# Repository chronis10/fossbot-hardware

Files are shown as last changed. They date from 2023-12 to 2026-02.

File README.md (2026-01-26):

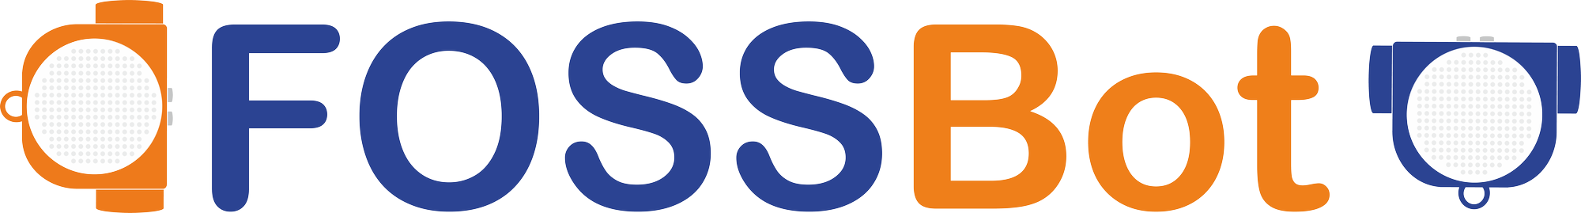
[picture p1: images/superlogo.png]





The newer version of the FOSSBot is available here, where you can find the 3D models and instructions to build it.

The redesign of the robot is complete, and the files are available for download.

The circuit schematics, instructions, and firmware code will be available soon.

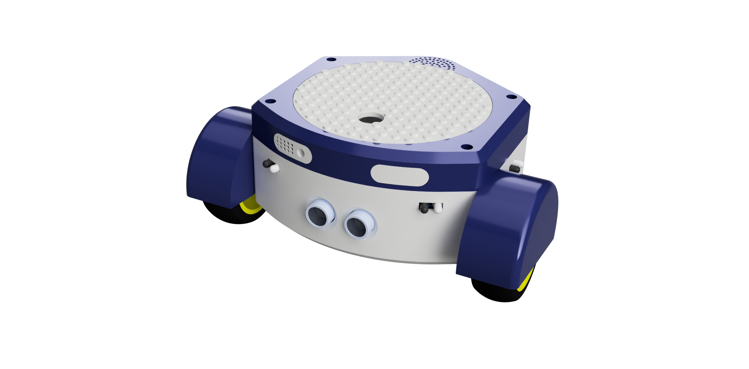
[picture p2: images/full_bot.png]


## 3D Printable Part List
---
* [Battery Cover](stl/batterycover.stl)
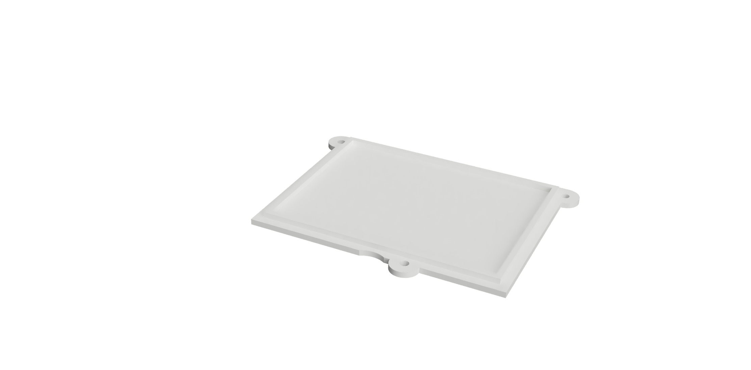
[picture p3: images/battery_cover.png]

---
* [Bottom Base](stl/b1_p_f.stl)
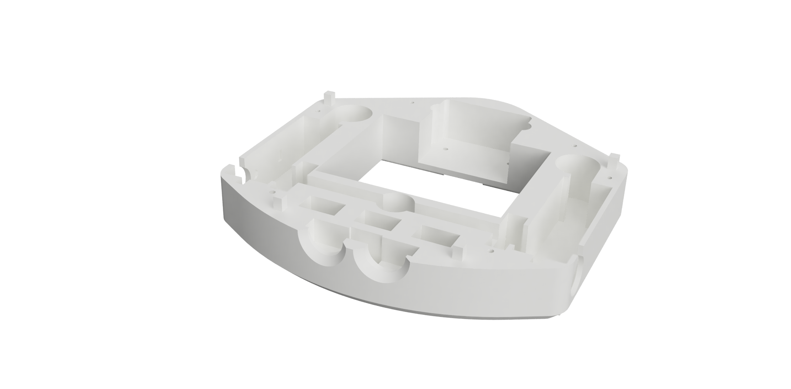
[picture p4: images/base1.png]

---
* [Middle Base](stl/b2_p_f.stl)
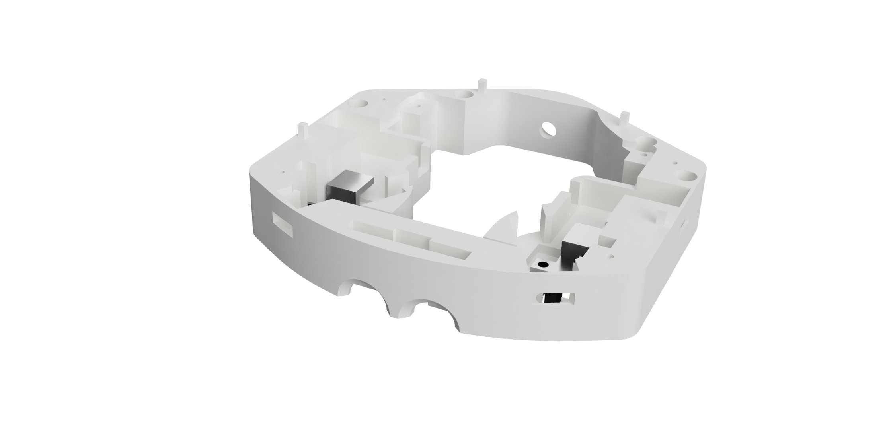
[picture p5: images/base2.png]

---
* [Top Base](stl/b3_p_f.stl)
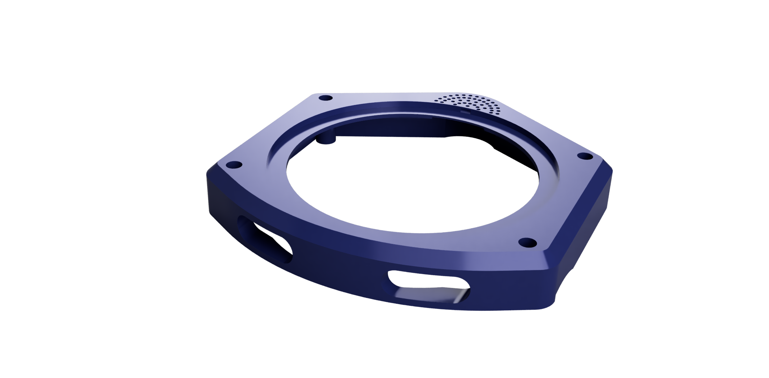
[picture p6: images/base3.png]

---
* [Left eye](stl/left_eye.stl)
* [Right eye](stl/right_eye.stl)
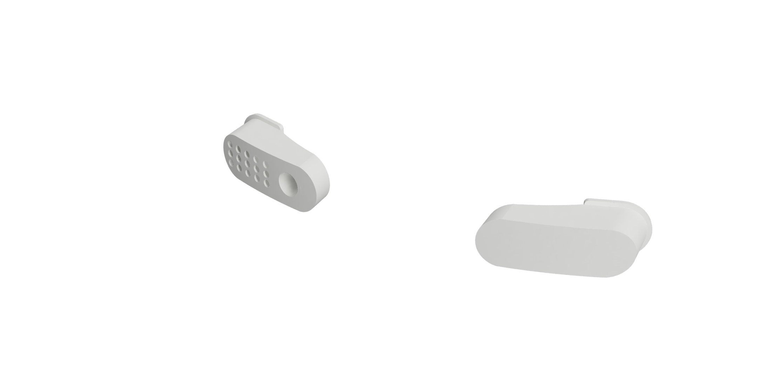
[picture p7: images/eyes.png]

---
* [Top Cover](stl/lego_top.stl)
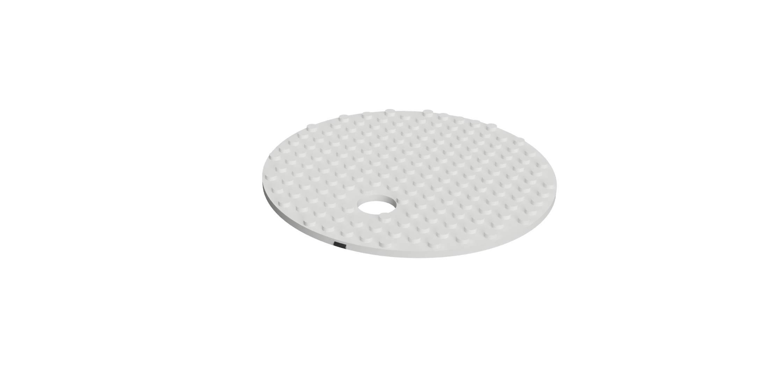
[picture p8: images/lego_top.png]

---
* [Pen Holder](stl/pen_holder.stl)
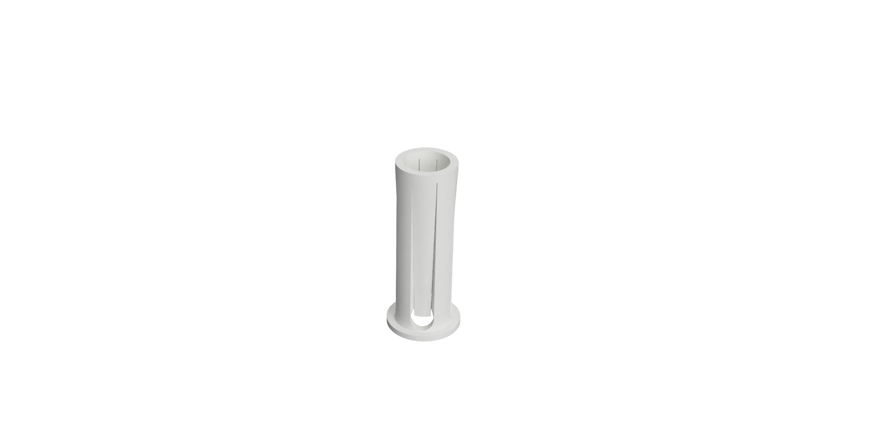
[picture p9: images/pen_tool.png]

---
* [Spoiler Left](stl/fender_left.stl)
* [Spoiler Right](stl/fender_right.stl)
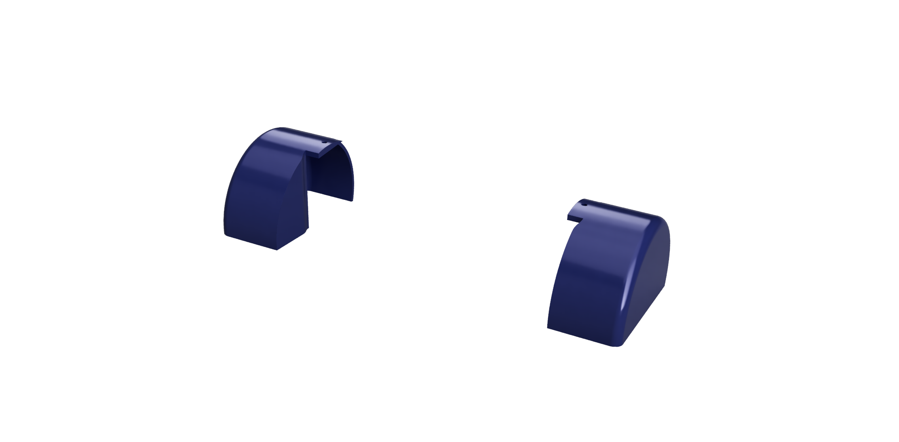
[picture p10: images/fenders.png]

---

## PCB
---
* [Main PCB production file](PCB/production/fossbot-v2-main-pcb.zip)
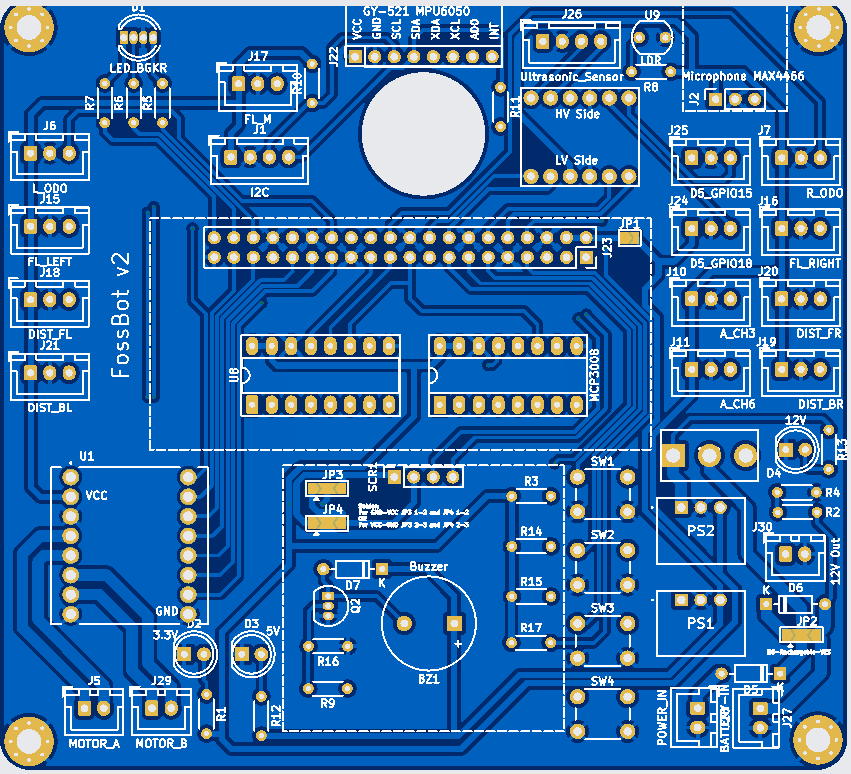
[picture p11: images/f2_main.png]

---
* [Battery module production file](PCB/production/battery_module.zip)
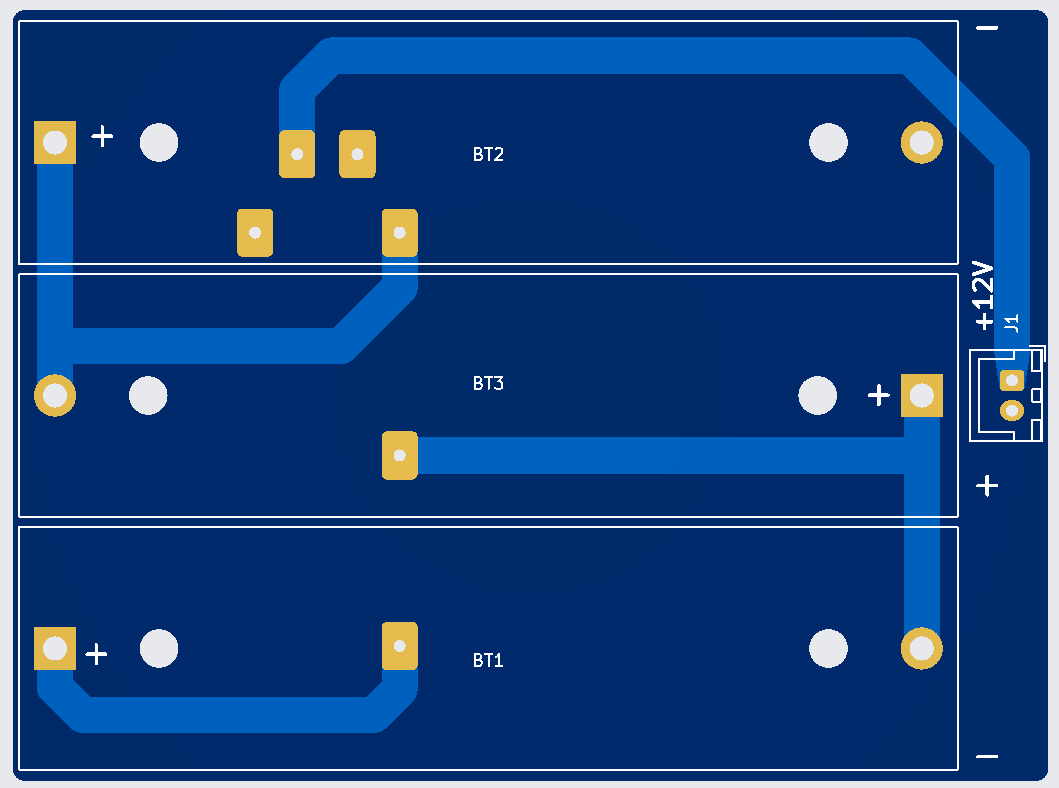
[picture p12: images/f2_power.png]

---

## Hardware/Software Development Team
* Christos Chronis
* Dimitris Charitos
* Adrien BRACQ - Barbatronic

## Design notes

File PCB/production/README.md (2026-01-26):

# Production Files

Upload these ZIP files directly to a manufacturer to produce the PCBs.
You can use https://jlcpcb.com/ , which has already been tested by our team with good results, but feel free to try alternative manufacturers.

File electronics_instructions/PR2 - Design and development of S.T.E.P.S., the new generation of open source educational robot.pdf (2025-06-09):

Design and development of S.T.E.P.S.,

# the new generation of open source educational robot

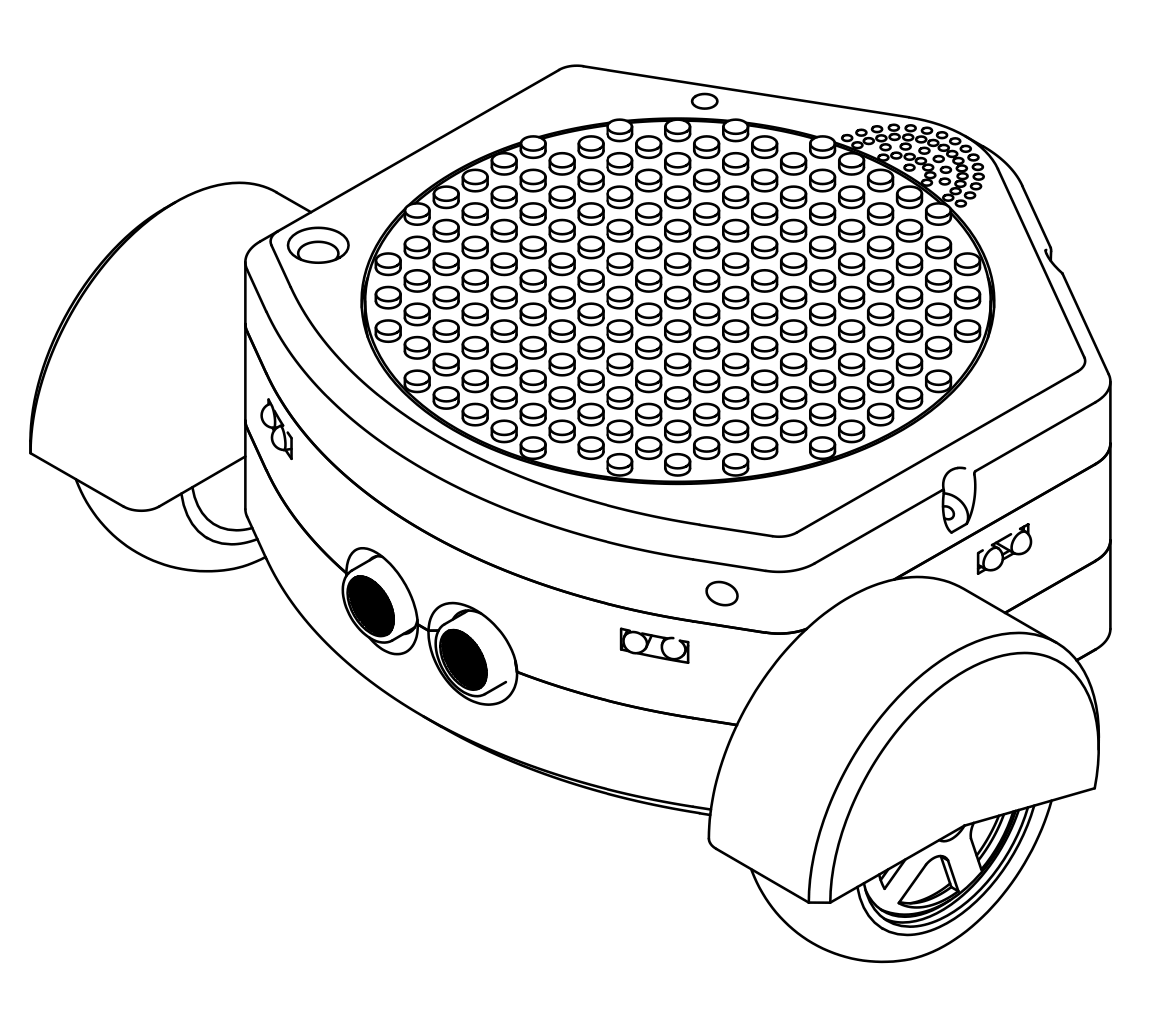
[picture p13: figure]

1. Executive Summary | 4
1.1. Overview of the S.T.E.P.S. project | 4
1.2. Objectives of the New Design | 5
1.3. Key Innovations and Improvements | 6
1.4. Target Audience and Use Cases | 8
2. Background and Inspiration | 9
2.1. Overview of FOSSBot: The Open-Source Educational Robot | 9
2.2. Limitations and Challenges of FOSSBot | 12
2.3. Desk Research Insights from 5 Countries | 12
2.4. Initial Aims: Simplification and Usability | 14
3. Design Philosophy and Goals | 17
3.1. Core Design Principles | 17
3.2. Focus on Open-Source and Accessibility | 17
3.3. Simplification of Assembly and Usage | 18
3.4. Modularity and Customizability | 19
3.5. Alignment with Educational Standards | 20
4. Development Process | 21
4.1. Conceptualization and Ideation | 21
4.2. Iterative Design and Prototyping | 21
4.3. Incorporating Feedback from Desk Research | 22
4.4. Collaboration with Open-Source Communities | 22
4.5. Challenges and Solutions | 22
5. Technical Design of the new FOSSBot | 24
5.1. Mechanical Design | 24
5.2. Electronics Design | 27
5.3 Software Architecture and Connectivity | 29
6. Key Features and Innovations | 31
6.1. Simplified Assembly Process | 31
6.2. Enhanced Durability and Usability | 31
6.3. Support for Multiple Programming Levels | 32
6.4. Expandable and Customizable Modules | 32
6.5. Cost-Effective and Open-Source Design | 32
7. Comparison with FOSSBot | 33
7.1. Design and Structural Improvements | 33
7.2. Enhanced Educational Features | 33
7.3. Usability and Accessibility Comparison | 33
7.4. Cost and Manufacturing Efficiency | 34
8. Conclusion | 35
8.1. Summary of Achievements | 35

8.2. Im

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
al R

o

b

o

tic

s

3

6
8.3. C

all t

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
# 1. Executive Summary

## 1.1. Overview of the S.T.E.P.S. project

S.T.E.P.S. (STEM Teaching and Education Platform for Students) is a project designed to democratize access to robotics and STEM education, utilizing open-source technologies and free software to make educational resources more accessible and customizable for students and educators from various backgrounds. Leveraging open-source solutions and tools, as well as the best practices of STEM education across several countries, it aims to make robotics and programming accessible to students and their educators.

At its core, S.T.E.P.S. provides low-cost, customizable educational robots that empower students and educators to explore robotics and programming in a hands-on manner. By leveraging open-source principles, the project ensures that its tools and resources are freely available, enabling widespread adoption even in underserved communities. Complementing the hardware, S.T.E.P.S. includes manuals, guidelines, sample programs, etc., offering free access to high-quality STEM learning resources, tutorials, and project ideas. This combination of physical and digital tools creates a comprehensive ecosystem for learning and innovation.

The project brings together experts from diverse fields, including robotics, education, software development, and sustainability, to collaboratively design tools, guidelines, and educational content tailored to a wide range of learners. By addressing Erasmus+ priorities, S.T.E.P.S. promotes digital transformation, inclusion, and diversity in education, ensuring that no one is left behind in the rapidly evolving digital landscape. The initiative is designed to support pre- and in-service secondary school teachers or trainers who aim to teach STEM and robotics to beginners, as well as students from all backgrounds, particularly those in secondary schools and beyond, who are eager to learn robotics and programming. Additionally, S.T.E.P.S. engages educational institutions, authorities, and policymakers to foster systemic change, while also involving parents or guardians who wish to support their children’s STEM education.

The project also welcomes community members, including local businesses and organizations, to contribute to STEM education initiatives in their areas, and it actively collaborates with open-source communities and developers to enhance the educational robot and MOOC platform. Furthermore, S.T.E.P.S. encourages primary school teachers to integrate STEM into their curriculum and invites university students or recent graduates to volunteer as mentors or instructors, creating a vibrant ecosystem of learning and collaboration. To align with global sustainability goals, the project incorporates green practices, such as using sustainable materials in robot production and adopting energy-efficient design principles. Through these efforts, S.T.E.P.S. not only advances STEM education but also embodies a forward-thinking, socially responsible approach that benefits learners, educators, and communities alike.

After performing an overview of open source software and hardware solutions and based on the previous experience of the team on designing educational robots, we decided to rely on the open source robot FOSSBot, and instead of designing a new robot from scratch, we decided to upgrade it.

## 1.2. Objectives of the New Design

The design of S.T.E.P.S. is driven by clear, measurable objectives aimed at making STEM education more accessible, engaging, and effective. These objectives focus on simplifying assembly and usage, enhancing educational value, promoting open-source collaboration, and ensuring affordability. Each objective is supported by specific design improvements and key performance indicators (KPIs) to track progress and success.

1. Simplify Assembly and Usage
One of the primary goals of S.T.E.P.S. is to reduce the complexity of building and operating the robot, making it accessible to beginners, including students and educators with limited technical expertise. To achieve this, the robot’s body and electronic components have been redesigned to allow for an easier assembly process. This includes modular components that snap together without the need for specialized tools, as well as clear, step-by-step instructions. Additionally, the project aims to reduce 3D printing time and material usage by optimizing the design for efficiency. Quantitative KPIs, such as the percentage reduction in printing materials and time, will be tracked to measure success. User feedback on the ease of assembly will also be collected through the LTTA workshops, ensuring continuous improvement based on real-world experiences.
2. Enhance Educational Value
S.T.E.P.S. is designed to provide a versatile platform that supports multiple programming levels, catering to users with varying skill levels. Beginners can start with the kindergarten mode which contains only 4 movement buttons and continue with block-based coding (using Blockly). The user interface (UI) is intuitive and adaptable, ensuring a seamless learning experience. To measure the success of this objective we will gather qualitative feedback through online surveys on the usability of the UI and its educational value. Additionally, the robot will feature new sensors, to expand its capabilities and applications.
3. Promote Open-Source Collaboration
S.T.E.P.S. is committed to fostering a vibrant open-source community where users can contribute to the development and improvement of the robot. By extending FOSSBot and generating FOSSBot 2.0, we will be able to encourage collaboration among educators, students, developers, and hobbyists. To further assist users who do not have the ability to print and assemble the robot immediately, we also provide a simulated version of the robot developed using CoppeliaSim. The digital twin allows users to simulate and test the robot in a virtual environment, further lowering barriers to entry. The simulated version and all design files, software, and documentation of the new robot are freely available through the FOSSBot github page (https://github.com/eellak/fossbot) Qualitative feedback from the community will be collected to assess the relevance and impact of the open-source approach.
4. Ensure Affordability
To enable widespread adoption, particularly in schools and underserved communities, the new FOSSBot is designed to be cost-effective. The optimized design reduces material and production costs, while the use of 3D printing allows for local manufacturing, further lowering expenses. Affordability will be measured through quantitative KPIs, such as the percentage reduction in material costs, and qualitative feedback from educators and institutions on the robot’s accessibility.

The success of FOSSBot redesign will be evaluated through a combination of quantitative and qualitative KPIs. Quantitative metrics include the percentage reduction in printing materials and time, the number of new sensors and expansion capabilities, the number of programming tools supported by the UI, and the number of downloads and users of the digital twin. Qualitative KPIs will focus on user feedback, collected through online surveys and assessing the ease of assembly, usability of the UI, educational value, and relevance to curricula. These metrics will ensure that the project remains aligned with its goals and continuously improves based on user needs.

By focusing on these objectives and tracking progress through well-defined KPIs, S.T.E.P.S. aims to create a transformative educational tool that empowers learners, supports educators, and fosters innovation in STEM education.

## 1.3. Key Innovations and Improvements

S.T.E.P.S. introduces a range of key innovations and improvements over the original FOSSBot, now referred to as FOSSBot 2.0. These advancements are designed to enhance functionality, usability, and accessibility, making the robot a more versatile and effective tool for STEM education. Below are the major innovations that define FOSSBot 2.0:

1. Integration of Raspberry Pi
One of the most significant upgrades in FOSSBot 2.0 is the integration of a Raspberry Pi as the main processing unit. This powerful microcontroller not only supports a wide range of sensors and peripherals but also allows the robot to function as a web server, hosting its own programming platform. This means users can program the robot directly through a web interface, eliminating the need for additional software installations. The Raspberry Pi’s versatility opens up new possibilities for advanced projects, such as data logging, machine learning, and IoT applications, making FOSSBot 2.0 a future-proof educational tool.
2. Wireless Connectivity
FOSSBot 2.0 introduces Wi-Fi connectivity, enabling users to connect to the robot wirelessly. This eliminates the need for cables or USB connections to transfer programs, making the robot more convenient and user-friendly. Wireless connectivity also allows for real-time control and monitoring, enhancing the interactive learning experience. Students can program and control the robot from their laptops, tablets, or smartphones, fostering a more flexible and engaging learning environment.
3. New PCB Design
The robot features a new printed circuit board (PCB) that integrates multiple circuits, significantly reducing the number of cables and connections required. This streamlined design not only simplifies assembly but also improves reliability by minimizing potential points of failure. The new PCB also includes JST clips for easy sensor attachment and replacement, making it easier for users to customize and upgrade the robot.
4. Modular Plastic Design
FOSSBot 2.0 incorporates a modular design for its 3D-printed plastic components, which minimizes assembly time and simplifies maintenance. The modular approach allows users to easily replace or upgrade individual parts without disassembling the entire robot. Additionally, the careful placement of sensors and cables reduces the overall size of the robot and optimizes printing time, making it more efficient to produce.
5. Simulation in CoppeliaSim
To lower the barrier to entry, FOSSBot 2.0 includes a digital twin simulation in CoppeliaSim. This allows users to program and test the robot in a virtual environment without the need for physical hardware. The simulation is particularly useful for educators and students who may not have immediate access to the robot, providing a no-cost way to explore its programming philosophy and capabilities.
6. LEGO-Compatible Top
The robot’s top panel is designed to be LEGO-compatible, enabling users to attach additional components and accessories. This feature encourages creativity and experimentation, allowing students to build custom extensions and integrate the robot with other LEGO-based projects. The top panel is also attached with magnets, making it easy to open and access the internal components for maintenance or upgrades.
7. Battery Compatibility and Accessibility
FOSSBot 2.0 supports rechargeable lithium batteries as well as other commonly available battery types, ensuring flexibility and accessibility for users with different resources. The battery compartment features a removable bottom cover, making it easy to replace batteries without disassembling the robot. This design choice enhances usability and ensures the robot can be powered by whatever batteries are readily available.
8. Robust and Durable Design
The robot’s sturdy and durable design ensures it can withstand the rigors of classroom use. The materials and construction are optimized for longevity, reducing the need for frequent repairs or replacements. This durability makes FOSSBot 2.0 a reliable tool for educators and students alike.
9. Additional Sensors and Expandability
FOSSBot 2.0 includes more sensors than its predecessor, expanding its capabilities for educational projects. The robot also features I2C connectivity, allowing for the easy integration of additional components and peripherals. This expandability ensures that the robot can grow with the user’s skills and interests, supporting more advanced projects as learners progress.
10. Improved Software Connectivity
The software architecture of FOSSBot 2.0 has been enhanced to improve connectivity and compatibility with various programming tools and platforms. This ensures a seamless experience for users, whether they are working with block-based coding environments like Blockly or text-based languages like Python and JavaScript.
11. Compact Size
The overall size of FOSSBot 2.0 has been reduced, making it more portable and easier to handle. Despite its smaller footprint, the robot retains all its functionality and expandability, ensuring it remains a powerful tool for STEM education.

These innovations collectively make FOSSBot 2.0 a cutting-edge educational robot that is easier to use, more versatile, and more accessible than ever before. By addressing the limitations of the original FOSSBot and incorporating user feedback, S.T.E.P.S. has created a tool that empowers learners and educators to explore the exciting world of robotics and programming.

## 1.4. Target Audience and Use Cases

S.T.E.P.S. is designed to cater to a diverse audience, ensuring that its benefits reach a wide range of users across educational and community settings. The robot and its accompanying resources are tailored to meet the needs of various target groups, each with unique goals and requirements.

1. Educators and Trainers
Pre- and in-service secondary school teachers or trainers form a core part of S.T.E.P.S.’s target audience. These educators are often tasked with introducing STEM and robotics to students at a beginner level but may lack the tools or confidence to do so effectively. S.T.E.P.S. addresses this challenge by providing an easy-to-assemble robot, comprehensive lesson plans, and a user-friendly programming interface. Teachers can use the robot to teach fundamental concepts in robotics, programming, and engineering, while also fostering problem-solving and critical thinking skills. Additionally, primary school teachers who wish to incorporate STEM education into their curriculum can leverage S.T.E.P.S. to introduce younger students to basic robotics concepts in an engaging and age-appropriate manner.
2. Students and Learners
Students from all backgrounds, particularly those in secondary schools and beyond, are a key focus of S.T.E.P.S. The robot is designed to be accessible to beginners, allowing students with no prior experience in robotics or programming to get started quickly. At the same time, its advanced features and expandable capabilities provide opportunities for more experienced learners to explore complex concepts and projects. By supporting multiple programming levels—from block-based coding for beginners to text-based programming for advanced users—S.T.E.P.S. ensures that students can progress at their own pace. The robot’s hands-on nature makes it an ideal tool for project-based learning, enabling students to apply theoretical knowledge to real-world challenges.
3. Institutions, Policymakers, and Community Stakeholders
Educational institutions and authorities play a crucial role in the adoption and implementation of STEM education initiatives. S.T.E.P.S. provides these stakeholders with a cost-effective, scalable solution that aligns with curriculum standards and promotes digital transformation. Policymakers can use the project as a model for integrating robotics and programming into national or regional education frameworks. Beyond formal education, community members, including local businesses and organizations, can support STEM education initiatives by sponsoring S.T.E.P.S. kits or hosting workshops. This collaborative approach helps build a strong ecosystem of learning and innovation at the community level.
4. Open-Source Contributors and Mentors
S.T.E.P.S. actively engages open-source communities and developers to contribute to the ongoing development and improvement of the robot and its accompanying MOOC platform. By making all design files, software, and documentation freely available, the project encourages collaboration and innovation. Additionally, university students or recent graduates can volunteer as mentors or instructors, sharing their expertise with younger learners and gaining valuable teaching experience. This not only enriches the learning experience for students but also fosters a sense of community and shared purpose among contributors.

Through its inclusive design and versatile applications, S.T.E.P.S. serves as a powerful tool for empowering learners, supporting educators, and engaging communities in the exciting world of STEM and robotics.

# 2. Background and Inspiration

## 2.1. Overview of FOSSBot: The Open-Source Educational Robot

FOSSBot is an educational robot that uses open software and hardware and can be employed at all levels of education. FOSSBot has been developed collaboratively by Harokopio University of Athens and GFOSS, and is an extension of "GSOC 2019 - A DIY robot kit for educators" https://github.com/eellak/gsoc2019-diyrobot. As a DIY (Do It Yourself) robot, FOSSBot is designed to be easily built, disassembled, and reassembled by users, making the construction process itself an integral part of the educational experience. The robot’s components are intentionally simple and affordable, with electronic parts that are commercially available at low cost and 3D-printable plastic parts, ensuring accessibility for schools, educators, and hobbyists.

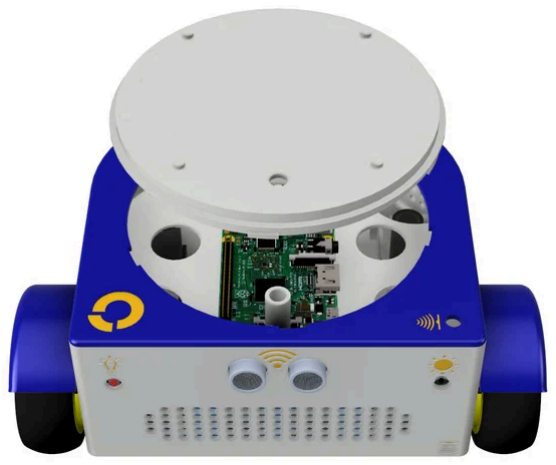
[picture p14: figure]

Figure 1. The top-view and internal aspect of FOSSBot’s initial design

FOSSBot is equipped with a variety of sensors and features that make it a powerful tool for teaching robotics and programming. Its sensors include an ultrasonic distance sensor, battery sensor, accelerometer, gyroscope, odometers, IR receiver, line detection sensors, and light sensors, enabling a wide range of educational activities and experiments. The robot also boasts interaction features such as a speaker, front RGB LED, and a top cover for attaching additional components. Practical design elements, like a hole in the front for marker or pencil attachment and a special pulling loop, further enhance its usability in classroom settings. Additionally, FOSSBot is powered by rechargeable batteries, making it an eco-friendly and cost-effective solution for hands-on learning. These features,combined with its open-source nature, make FOSSBot a highly adaptable and engaging platform for STEM education.

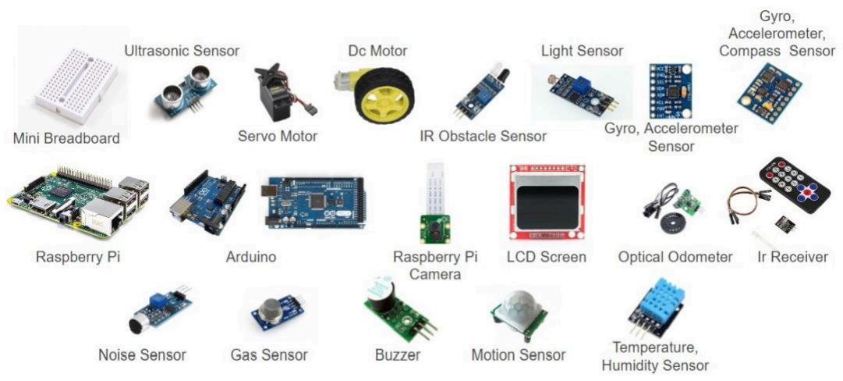
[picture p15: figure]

Figure 2. The list of FOSSBot electronics

FOSSBot is operated on a modular software stack that enables a variety of operation and programming modes, seamless orchestration through its administration GUI, and straightforward hardware control via a Python-based software library that functions as the robot’s operating system. The stack integrates several interconnected components, including Google Blockly for block-based programming, Python Jupyter for interactive coding, and Python Flask, which hosts the administration and supervisor GUI. At its core, FOSSBot relies on a Python library that abstracts hardware control, allowing users to easily command the robot’s movements, sensors, and actuators. This core library is accessible to all programming and operation modules, ensuring a unified and flexible development environment. The administration container oversees the robot’s normal operation, enabling users to modify default parameters and maintain the system. While FOSSBot’s current capabilities focus on basic 2D movement and sensor data collection, future development aims to expand its functionality with advanced features such as path planning and computer vision. Additionally, the system supports no-coding and block-based coding modes through a middleware interface that wraps core functionalities into REST API calls, ensuring accessibility for users of all skill levels. This modular and extensible architecture positions FOSSBot as a versatile platform for educational robotics.

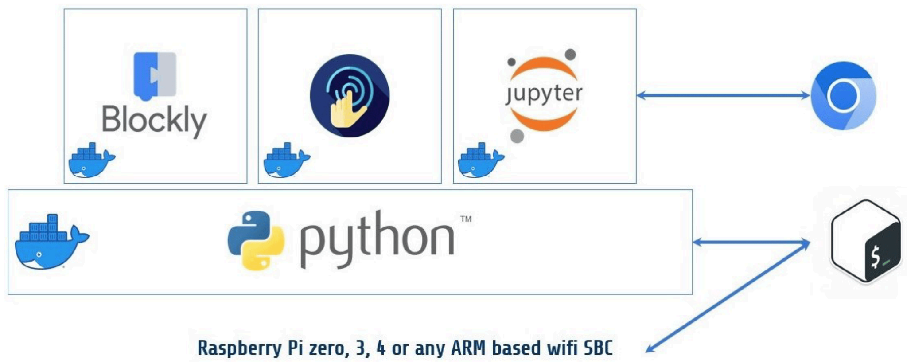
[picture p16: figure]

Figure 3. The programming stack of FOSSBot

FOSSBot offers four distinct programming modes, each tailored to different skill levels and educational needs. The first mode, No-Coding Mode, is designed for users with little or no programming experience, such as pre-school children. In this mode, the robot is operated through a simple graphical interface with buttons that control basic movements like forward, backward, and rotational steps. Educators can customize this interface by adding new buttons linked to pre-defined or block-based scripts, enabling activities like line-following or sound playback. This mode not only introduces young learners to robotics but also allows educators to adjust the complexity of tasks based on the students’ progress. The second mode, Block-Based Coding Mode, is ideal for primary school students and is built on the open-source Google Blockly platform. Here, users create programs by connecting coding blocks that represent commands, such as movement, sensor interactions, and LED control. These blocks are mapped to Python methods in the core FOSSBot library, allowing students to control the robot’s hardware without writing code. The block-based scripts can be saved, modified, and even linked to buttons in the No-Coding Mode, providing a seamless transition between modes. This approach fosters computational thinking and problem-solving skills in a visual and intuitive way. Together, these two modes make FOSSBot accessible to beginners while gradually preparing them for more advanced programming challenges.

## 2.2. Limitations and Challenges of FOSSBot

Despite its innovative design and educational potential, the original FOSSBot faced several limitations and challenges that hindered its accessibility and usability, particularly for beginners and educators with limited technical expertise. One of the most significant issues was the complexity of assembly, which required users to manually connect multiple electronic components without the aid of a printed circuit board (PCB). This not only increased the risk of wiring errors but also made the assembly process time-consuming and intimidating for those unfamiliar with electronics. Additionally, the 3D printing of plastic parts was both time-intensive and material-heavy, further delaying the readiness of the robot for classroom use. These factors combined to create a steep learning curve, limiting FOSSBot’s adoption in educational settings where simplicity and ease of use are critical.
Another challenge was the lack of modularity and user-friendly design in the original FOSSBot. The absence of a unified PCB meant that cables and connections were exposed and prone to disconnection, making the robot less durable and harder to maintain. Furthermore, the assembly process required specialized tools and a certain level of technical skill, which posed a barrier for educators and students who were not familiar with electronics or robotics. The long printing and assembly times also made it difficult to integrate FOSSBot into time-constrained classroom activities, reducing its practicality as an educational tool. Additionally, the battery charging circuit added to the cost and complexity of the robot, as it required specific components and careful assembly, further limiting its accessibility for schools with limited budgets or technical resources.
A notable usability challenge was the initial connection process, which required users to connect to FOSSBot as a hotspot. While this allowed for wireless interaction, the setup process was not always intuitive, especially for younger students or educators unfamiliar with networking concepts. This created a barrier to entry, as users had to navigate multiple steps to establish a connection before they could begin programming or controlling the robot. Moreover, while FOSSBot offered multiple programming modes, not all of them were equally useful or relevant for its primary target audience of primary and secondary education. For example, the Python programming mode, which provided low-level control over the robot, was often too advanced for younger students, while the no-coding and block-based modes were more aligned with their skill levels. This mismatch in programming modes highlighted the need for a more focused and streamlined approach to ensure that the robot’s features were both accessible and educationally relevant for its intended users.
These challenges underscored the importance of redesigning FOSSBot to address these pain points, leading to the development of FOSSBot 2.0, which incorporates a new PCB, modular design, simplified battery compatibility, and a more intuitive connection process. By focusing on the needs of primary and secondary education, FOSSBot 2.0 aims to overcome these limitations and make STEM education more inclusive, engaging, and effective.

## 2.3. Desk Research Insights from 5 Countries

The development of S.T.E.P.S. and the redesign of FOSSBot were informed by extensive desk research conducted across five countries: France, Greece, Poland, Spain, and Turkey. This research, which included a review of educational policies, curricula, and best practices, highlighted both the opportunities and challenges of integrating educational robotics (ER) and STEM education into school systems. A key resource in this research was the book chapter that has been published by the S.T.E.P.S. consortium in a Springer Palgrave book. The chapter was titled "Theoretical and Practical Coherence of Integrated STEM Education and Educational Robotics: Review and Analysis of Good Practices in Europe", co-authored by experts from the S.T.E.P.S. project. This chapter analyzed ten best practices in ER and STEM education across Europe, identifying common trends, challenges, and areas for improvement.
The desk research analyzed 50 good practices across the five European countries, focusing on four key parameters: teaching methodologies, promotion of co-education, types of robots used, and integration of STEM areas. The findings revealed that cooperative and collaborative learning was the most prevalent teaching methodology, used in 46 out of 50 practices, followed by constructionism (23 practices) and project-based learning (PBL) (21 practices). These methodologies emphasize interactive, hands-on, and group-based learning, which are highly effective in engaging students and fostering critical thinking. However, the research also highlighted a significant gap in co-education, with 88% of practices failing to address gender equality. This underscores the need for more initiatives to encourage girls to pursue STEM studies and ensure inclusivity in robotics education.
In terms of robotic resources, the analysis showed a preference for custom-built robots and Lego Mindstorms kits, each used in 15 practices, while Arduino boards were utilized in 6 practices. This indicates a trend toward both low-cost, customizable solutions and commercially available kits, depending on the educational context. The integration of STEM disciplines varied, with technology and engineering being the most commonly integrated areas (over 90% of practices), followed by science (70%) and mathematics (62%). This suggests that while robotics naturally aligns with technology and engineering, there is room for improvement in integrating mathematics and science more cohesively into ER activities.
The research also examined the good practices by country, revealing distinct trends and preferences. For example:
- France favored self-built robots using low-cost materials and emphasized cooperative learning and constructionism. However, it lagged in integrating mathematics and science into its practices.
- Spain and Greece showed a strong preference for Lego Mindstorms kits and project-based learning, with Spain also leading in the promotion of co-education.
- Poland stood out for its diverse use of robot types and its focus on co-education, with four practices explicitly addressing gender equality.
- Turkey and Greece demonstrated robust integration of all four STEM areas, though Turkey faced challenges in teacher training and resource accessibility.
One of the most significant findings was the lack of compulsory integration of ER into national curricula across Europe. While countries like Spain and France have made strides in incorporating robotics into their educational frameworks, ER is often relegated to extracurricular activities, weekend workshops, or summer camps. For example, Spain’s 2022 Royal Decree introduced a compulsory "computational thinking, automation, and robotics" block in secondary education, but similar mandates are rare in other countries. In Greece, robotics is taught within the context of informatics and supported by initiatives like the "Skills Workshops" program, but it remains optional. This inconsistency highlights the need for a more standardized approach to ER integration, ensuring that all students, regardless of location or socio-economic status, have access to robotics education.

The research also revealed common barriers to ER adoption, including high equipment costs, lack of trained teachers, and insufficient infrastructure. For instance, while France’s 2015 Digital Plan for Education accelerated the integration of robotics, many schools still struggle with the cost of commercial robot kits and the need for specialized laboratories. Similarly, in Turkey, despite significant advancements in STEM education through initiatives like TÜBİTAK and TEKNOFEST, challenges such as unequal access to resources and inadequate teacher training persist. These findings underscored the importance of developing low-cost, open-source solutions like FOSSBot, which can be easily replicated and adapted to different educational contexts.
Another critical insight was the need for interdisciplinary and project-based learning in STEM education. The reviewed best practices emphasized the importance of integrating at least two STEM disciplines in a cohesive manner, using methodologies like inquiry-based learning and the engineering design process. For example, Poland’s educational policy promotes an interdisciplinary approach that combines sciences and arts, fostering creativity and critical thinking. Similarly, Greece’s recent investment in robotics and STEM equipment, funded by the EU’s National Recovery and Resilience Plan, aims to enhance hands-on, collaborative learning experiences. These findings informed the design of S.T.E.P.S., which emphasizes modularity, expandability, and the use of open-source tools to support diverse educational activities.
The research also highlighted the gender gap in STEM and robotics education, with a notable lack of initiatives aimed at encouraging girls to pursue STEM studies. While countries like Turkey have made efforts to promote co-education and gender equality in STEM, more work is needed to address this issue across Europe. This insight reinforced the need for inclusive design and educational content that appeals to all students, regardless of gender.
Finally, the desk research underscored the importance of teacher training and support in successfully implementing ER and STEM education. Many of the challenges identified, such as the lack of robotics teachers and the complexity of integrating new technologies into the classroom, can be addressed through targeted professional development programs. The S.T.E.P.S. project addresses this need by providing comprehensive resources, including a MOOC platform and a digital twin simulation, to support educators in using FOSSBot effectively. In summary, the desk research provided valuable insights into the current state of ER and STEM education in Europe, highlighting both the progress made and the challenges that remain. These findings directly informed the design and development of S.T.E.P.S., ensuring that the project addresses real-world needs and promotes inclusive, accessible, and effective STEM education for all.

## 2.4. Initial Aims: Simplification and Usability

The redesign of FOSSBot into FOSSBot 2.0 was driven by a set of clear initial aims focused on simplifying assembly and usage, enhancing educational value, and ensuring affordability. These aims were informed by the limitations of the original FOSSBot, as well as insights from desk research across five European countries, which highlighted the need for a more accessible and user-friendly educational robot. The overarching goal was to create a tool that could be easily adopted by educators and students, regardless of their technical expertise or access to resources.

Simplifying Assembly and Usage
One of the primary objectives was to reduce the complexity of building and operating the robot, making it accessible to beginners, including students and educators with limited technical skills.

The original FOSSBot required users to manually connect multiple electronic components without a printed circuit board (PCB), leading to a time-consuming and error-prone assembly process. To address this, FOSSBot 2.0 incorporates a new PCB design that integrates multiple circuits, significantly reducing the number of cables and connections. This not only simplifies assembly but also improves the robot’s durability and reliability. Additionally, the modular design of the 3D-printed plastic parts minimizes assembly time and allows users to easily replace or upgrade individual components without disassembling the entire robot. These improvements ensure that FOSSBot 2.0 can be quickly and efficiently assembled, even by users with no prior experience in robotics or electronics.

Enhancing Educational Value
Another key aim was to enhance the educational value of FOSSBot by providing a platform that supports multiple programming levels, from beginners to advanced users. The original FOSSBot offered four programming modes, but not all were equally useful for its target audience of primary and secondary education. FOSSBot 2.0 addresses this by refining its no-coding and block-based coding modes, which are ideal for younger students, while also supporting more advanced programming in Python for older students. The integration of Raspberry Pi as the main processing unit further enhances the robot’s capabilities, enabling advanced projects such as data logging, machine learning, and IoT applications. Additionally, the inclusion of new sensors and peripherals, such as cameras and I2C-compatible components, expands the robot’s functionality, allowing for a wider range of educational activities and experiments.

Ensuring Affordability
To make FOSSBot 2.0 accessible to schools and underserved communities, the redesign focused on reducing costs without compromising functionality. The optimized design minimizes material and production costs, while the use of 3D printing allows for local manufacturing, further lowering expenses. The robot’s battery compatibility was also simplified, supporting rechargeable lithium batteries as well as other commonly available battery types. This ensures that users can power the robot with whatever resources are readily available, reducing the financial burden on schools and educators.

Addressing Usability Challenges
The original FOSSBot faced usability challenges, particularly with its initial connection process, which required users to connect to the robot as a hotspot. While this allowed for wireless interaction, the setup process was not always intuitive, especially for younger students or educators unfamiliar with networking concepts. FOSSBot 2.0 addresses this by streamlining the connection process and providing a more user-friendly interface for programming and controlling the robot. The inclusion of a digital twin simulation in CoppeliaSim further lowers the barrier to entry, allowing users to program and test the robot in a virtual environment before working with the physical hardware.

Promoting Inclusivity and Co-Education
Insights from the desk research highlighted the gender gap in STEM and robotics education, with a notable lack of initiatives aimed at encouraging girls to pursue STEM studies. FOSSBot 2.0 addresses this by incorporating inclusive design principles and educational content that appeals to all students, regardless of gender. The robot’s LEGO-compatible top panel and modular design encourage creativity and experimentation, making it an engaging tool for both boys and girls. Additionally, the project emphasizes co-education by providing resources and activities that promote gender equality in STEM education.

Supporting Teacher Training and Professional Development
Finally, the redesign of FOSSBot 2.0 recognizes the importance of teacher training and support in successfully implementing ER and STEM education. Many of the challenges identified in the desk research, such as the lack of robotics teachers and the complexity of integrating new technologies into the classroom, can be addressed through targeted professional development programs. The S.T.E.P.S. project provides comprehensive resources, including a MOOC platform and digital twin simulation, to support educators in using FOSSBot effectively. These resources ensure that teachers have the knowledge and tools they need to integrate robotics into their curriculum and engage students in hands-on, project-based learning.
By focusing on these initial aims, FOSSBot 2.0 overcomes the limitations of its predecessor and provides a more accessible, versatile, and effective tool for STEM education. The redesign ensures that the robot is not only easier to assemble and use but also more aligned with the needs of educators and students, making it a valuable resource for promoting inclusive and engaging STEM learning experiences.

# 3. Design Philosophy and Goals

The design of FOSSBot 2.0 is guided by a clear philosophy and set of goals aimed at creating an accessible, versatile, and effective educational tool for STEM learning. These principles ensure that the robot meets the needs of diverse users, from students and educators to hobbyists and researchers, while promoting inclusivity, affordability, and innovation in robotics education.

## 3.1. Core Design Principles

The core design principles of FOSSBot 2.0 are rooted in simplicity, accessibility, and educational value, ensuring that the robot is both easy to use and highly effective as a teaching tool. At its heart, FOSSBot 2.0 is designed to lower the barriers to entry for robotics and STEM education, making it accessible to students and educators with varying levels of technical expertise. This is achieved through a modular and intuitive design, which simplifies assembly and operation, and a user-friendly programming interface that supports multiple skill levels, from no-coding modes for beginners to advanced Python scripting for more experienced users. By prioritizing ease of use, FOSSBot 2.0 ensures that even those with no prior experience in robotics can quickly get started and engage in meaningful learning activities.
In addition to accessibility, FOSSBot 2.0 emphasizes durability, reliability, and adaptability. The robot is built to withstand the rigors of classroom use, with robust materials and a streamlined design that minimizes wear and tear. Its open-source architecture encourages collaboration and innovation, allowing users to customize and expand its capabilities to suit their specific needs. Furthermore, the robot’s alignment with educational standards ensures that it can be seamlessly integrated into existing curricula, supporting a wide range of STEM learning objectives. These core principles guide every aspect of FOSSBot 2.0’s design, making it a versatile and impactful tool for fostering creativity, critical thinking, and problem-solving skills in learners of all ages.

## 3.2. Focus on Open-Source and Accessibility

FOSSBot 2.0 is built on the foundation of open-source hardware and software, ensuring that all design files, code, and documentation are freely available to the public. This approach not only reduces costs but also fosters a collaborative community where educators, students, and developers can contribute to the robot’s development and improvement. By making the robot’s components 3D-printable and its software openly accessible, FOSSBot 2.0 eliminates the financial and technical barriers often associated with educational robotics. This democratizes access to robotics education, enabling schools and individuals with limited budgets to participate in STEM learning. Additionally, the digital twin simulation in CoppeliaSim provides a no-cost entry point for users who may not have immediate access to the physical robot, further enhancing accessibility.
The open-source nature of FOSSBot 2.0 also encourages innovation and customization. Users can modify the robot’s design, add new features, or integrate it with other platforms, such as Raspberry Pi or Arduino, to suit their specific educational needs. This flexibility ensures that FOSSBot 2.0 remains relevant and adaptable to evolving educational trends and technologies. Moreover, the project’s MOOC platform offers free access to STEM learning resources, tutorials, and project ideas, supporting educators and students in their robotics journey. By embracing open-source principles, FOSSBot 2.0 not only makes robotics education more accessible but also empowers users to take ownership of their learning experience, fostering a culture of collaboration and innovation.

## 3.3. Simplification of Assembly and Usage

One of the primary goals of FOSSBot 2.0 is to simplify the assembly and usage process, making the robot accessible to users of all skill levels. The original FOSSBot required manual wiring and complex assembly, which posed a significant barrier for beginners. FOSSBot 2.0 addresses this challenge with a new PCB design, with names to all connections and an integration of multiple circuits that reduces the number of cables and connections. This streamlined design not only simplifies assembly but also improves the robot’s reliability by minimizing potential points of failure. Additionally, the modular plastic components are designed to snap together easily, eliminating the need for specialized tools and reducing assembly time. These improvements ensure that even users with no prior experience in robotics or electronics can quickly and efficiently assemble the robot.

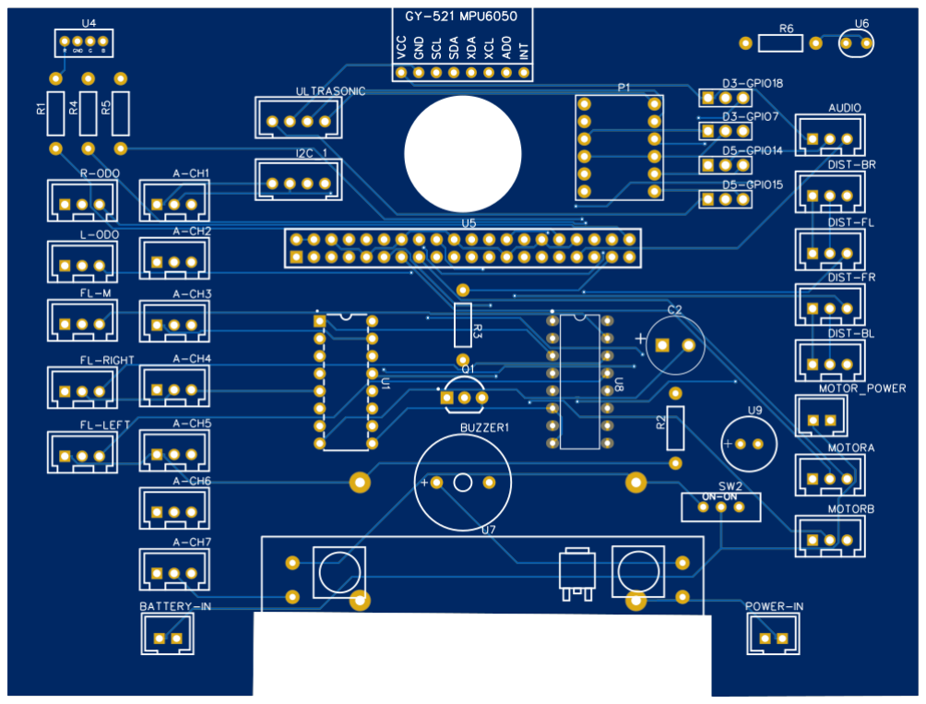
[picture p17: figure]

Figure 4. The design of the new PCB Beyond assembly, FOSSBot 2.0 focuses on simplifying the user experience through intuitive programming interfaces and streamlined operation. The robot supports no-coding and block-based coding modes, which are ideal for younger students and beginners, as well as more advanced programming options like Python for older students. The administration GUI provides a user-friendly interface for controlling the robot and modifying default parameters, while the wireless connectivity eliminates the need for cables or USB connections, making the robot easily connectable to the local network and more convenient to use. These features ensure that FOSSBot 2.0 is not only easy to assemble but also straightforward to operate, enabling educators and students to focus on learning and experimentation rather than technical setup. By prioritizing simplicity and usability, FOSSBot 2.0 removes the intimidation factor often associated with robotics, making STEM education more approachable and engaging for all.

## 3.4. Modularity and Customizability

FOSSBot 2.0 is designed with modularity and customizability at its core, ensuring that the robot can be easily adapted to meet the diverse needs of educators and students. The hardware design is divided into three main modular parts: the base, the middle section, and the top cover. The base houses the motors, wheels, and battery compartment, providing the robot with mobility and power. The middle section contains the main electronics, including the Raspberry Pi, sensors, and the new integrated PCB, which simplifies wiring and reduces assembly complexity. The top cover is designed to be LEGO-compatible, allowing users to attach additional components or accessories, fostering creativity and experimentation. As shown in Figure 5, the plastic parts of the robot are fewer and easier to assemble in only 7 steps. This modular design not only makes assembly and maintenance easier but also enables users to customize the robot for specific projects or learning objectives.

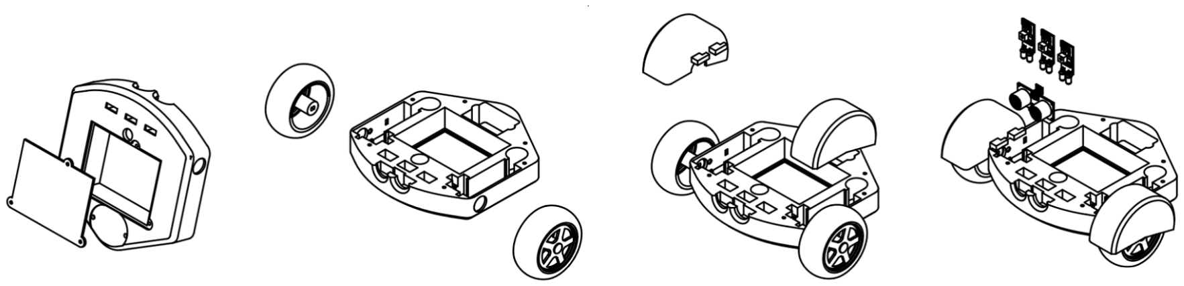
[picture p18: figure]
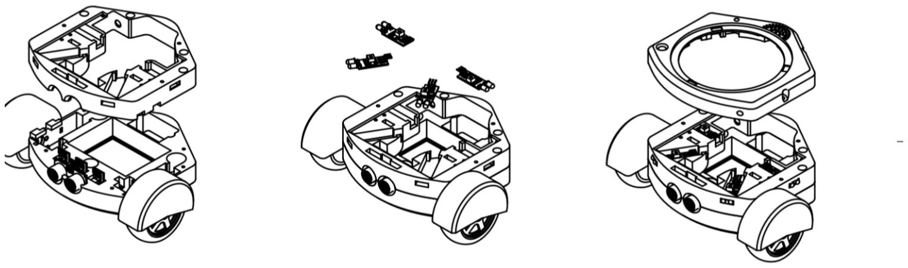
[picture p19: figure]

Figure 5. FOSSBot assembly in 7 steps The integrated PCB is a key feature of FOSSBot 2.0’s modularity, as it consolidates multiple circuits into a single board, reducing the number of cables and connections. This not only simplifies the assembly process but also improves the robot’s reliability by minimizing potential points of failure. The PCB includes JST clips for easy sensor attachment and replacement, making it simple for users to upgrade or modify the robot’s capabilities. Additionally, the I2C connectivity allows for the integration of additional sensors and peripherals, enabling advanced projects such as computer vision or environmental monitoring. This modular hardware design ensures that FOSSBot 2.0 can grow with the user’s skills and interests, supporting a wide range of educational activities and applications.

The software architecture of FOSSBot 2.0 is equally modular, building on a core Python library that controls the robot’s main operations, including movement, sensor data collection, and actuator control. This library provides a high level of abstraction, making it easy for users to command the robot’s hardware without needing to understand the underlying electronics. On top of this core library, the modular software stack includes additional layers that support the robot’s programming interfaces. The administration GUI, built using Python Flask, allows users to control the robot and modify default parameters through a user-friendly web interface. The Blockly-based programming interface provides a visual, drag-and-drop environment for creating programs, which are then converted into Python code and executed by the core library. This modular software stack ensures that FOSSBot 2.0 is accessible to users of all skill levels, from beginners using no-coding or block-based modes to advanced users writing custom Python scripts. By combining modular hardware and software, FOSSBot 2.0 offers unparalleled flexibility and customizability, making it a versatile tool for STEM education.

## 3.5. Alignment with Educational Standards

FOSSBot 2.0 is meticulously designed to align with national and international educational standards, ensuring seamless integration into formal and informal STEM curricula. For example, in Spain, the robot aligns with Royal Decree 217/2022, which mandates the inclusion of "computational thinking, automation, and robotics" in secondary education. FOSSBot’s programming modes, from no-coding to Python scripting, directly support the development of computational thinking and problem-solving skills outlined in this standard. Similarly, in France, the robot aligns with the Digital Strategy for Education 2023-2027, which emphasizes hands-on digital literacy and project-based learning. FOSSBot’s modular design and sensor-driven activities mirror the strategy’s focus on fostering technical understanding and creativity through interactive experimentation.

Globally, FOSSBot 2.0 aligns with the EU’s DigComp Framework, which identifies digital competence as a key skill for lifelong learning. The robot’s Blockly-based coding interface and Raspberry Pi integration address competencies such as "computational thinking" (DigComp 2.2) and "digital content creation" (DigComp 3.3). Additionally, FOSSBot supports NGSS (Next Generation Science Standards) in science and engineering, particularly practices like "analyzing data" (NGSS Practice 4) and "designing solutions" (NGSS Practice 6), through sensor-based experiments and project-based challenges. For instance, students can use the robot’s ultrasonic sensor to collect environmental data, analyze it with Python scripts, and design solutions to real-world problems, directly tying into cross-disciplinary STEM objectives.

# 4. Development Process

The development of FOSSBot 2.0 was a collaborative and iterative process, driven by user feedback, desk research, and a commitment to open-source principles. This section outlines the key stages of the development process, from initial conceptualization to overcoming challenges, and highlights how the project evolved to meet its goals of accessibility, usability, and educational relevance.

## 4.1. Conceptualization and Ideation

The development of FOSSBot 2.0 began with the conceptualization and ideation phase, where the team aimed to build upon the existing open-source FOSSBot to create a more advanced and user-friendly educational robot. The initial concept was to take the original FOSSBot, which was already a versatile tool for STEM education, and enhance it to meet the specific goals of the S.T.E.P.S. project. This included addressing limitations such as complex assembly, long printing times, and limited sensor support, while also incorporating new features like wireless connectivity, modularity, and advanced programming capabilities. The team conducted a thorough review of existing educational robots, both open-source and commercial, to identify best practices and areas for improvement. This research informed the design goals, which focused on creating a robot that was not only affordable and easy to use but also adaptable to diverse educational contexts.
The ideation phase also involved engaging with educators to understand their needs and preferences. Through desk research, the team identified over 50 best practices in educational robotics across the five participating countries (France, Greece, Poland, Spain, and Turkey). These practices highlighted the importance of project-based learning, interdisciplinary integration, and low-cost solutions, which became key pillars of FOSSBot 2.0’s design. Additionally, the team recognized the need to address the gender gap in STEM education and ensure that the robot appealed to all students, regardless of gender or technical background. This phase laid the foundation for a robot that would not only meet educational standards but also inspire creativity and innovation in learners.

## 4.2. Iterative Design and Prototyping

The development of FOSSBot 2.0 followed an iterative design and prototyping process, where multiple versions of the robot were created and tested to refine its features and functionality. The first prototypes focused on addressing the assembly complexity of the original FOSSBot by introducing a modular design with three main parts: the base, middle section, and top cover. This modular approach allowed for easier assembly and maintenance, while also enabling users to customize the robot for specific projects. The team also developed a new PCB to simplify wiring and reduce the number of connections, making the robot more reliable and user-friendly.
Throughout the prototyping phase, the team conducted three training sessions with educators from the participating countries, using the initial FOSSBot to gather feedback. These sessions employed the FUFU (Formative Usability Feedback and Usability) analysis method, which provided valuable insights into the robot’s usability and educational value. Educators highlighted the need for shorter printing times, better sensor integration, and more intuitive programming interfaces, which were incorporated into subsequent prototypes. The iterative process also involved testing the robot in real-world classroom settings, where educators and students provided feedback on its performance and usability. This hands-on approach ensured that FOSSBot 2.0 evolved to meet the practical needs of its users.

## 4.3. Incorporating Feedback from Desk Research

The desk research conducted across the five participating countries played a crucial role in shaping the design and functionality of FOSSBot 2.0. The research identified 10 best practices from each country, which were analyzed to identify common trends and challenges in educational robotics. One of the key findings was the preference for low-cost, customizable solutions over expensive commercial kits, which often lacked flexibility. This insight reinforced the team’s commitment to open-source principles and informed the decision to make FOSSBot 2.0’s design files and software freely available. Additionally, the research highlighted the importance of project-based learning and interdisciplinary integration, which were incorporated into the robot’s programming modes and sensor suite.
The feedback from educators also revealed a strong demand for simplified assembly and usage, as well as better support for teacher training. To address these needs, the team developed a digital twin simulation in CoppeliaSim, allowing users to program and test the robot in a virtual environment before working with the physical hardware. This feature not only lowered the barrier to entry but also provided a valuable tool for teacher training and professional development. By incorporating feedback from desk research and user testing, FOSSBot 2.0 was able to address the real-world challenges faced by educators and students, ensuring its relevance and effectiveness in diverse educational settings.

## 4.4. Collaboration with Open-Source Communities

A key aspect of FOSSBot 2.0’s development was its collaboration with open-source communities, which played a vital role in refining the robot’s design and functionality. The team actively engaged with educators, developers, and hobbyists through online platforms, workshops, and training sessions, gathering feedback and suggestions for improvement. In Greece, for example, the team collaborated with a network of over 500 educators who were trained using the simulation environment, as well as a dozen educators who received and used the physical robot. This collaboration provided valuable insights into the robot’s usability and educational value, which were used to refine its design and features.
The open-source nature of FOSSBot 2.0 also encouraged contributions from the broader community, with developers and educators proposing new features, fixing bugs, and creating educational content. This collaborative approach not only improved the robot’s functionality but also fostered a sense of ownership and engagement among users. By leveraging the expertise and creativity of open-source communities, FOSSBot 2.0 was able to evolve into a more robust and versatile tool for STEM education.

## 4.5. Challenges and Solutions

The development of FOSSBot 2.0 was not without its challenges. One of the main obstacles was the preference of educators for popular commercial robots, which are often closed-source and difficult to customize. To address this, the team emphasized the advantages of FOSSBot 2.0, including its lower cost, greater flexibility, and open-source design, which allows users to modify and expand its capabilities. The team also highlighted the digital twin simulation, which provides an easy entry point for users who may be hesitant to adopt a new platform.

Another challenge was ensuring that FOSSBot 2.0 met the diverse needs of educators and students across different countries and educational contexts. To overcome this, the team adopted a user-centered design approach, incorporating feedback from educators and students throughout the development process. This iterative approach ensured that the robot was not only easy to use but also aligned with educational standards and curricula. By addressing these challenges through collaboration, innovation, and a commitment to open-source principles, the team was able to create a robot that meets the needs of its users and supports the goals of the S.T.E.P.S. project.

# 5. Technical Design of the new FOSSBot

The technical design of FOSSBot 2.0 significantly improves the original FOSSBot, prioritizing ease of assembly and reliability. Predefined slots are incorporated into the robot structure to clearly indicate component placements, resulting in a more intuitive assembly process. Furthermore, the 3D printing process is optimized to substantially reduce print failures. Components are redesigned to facilitate straightforward attachment and detachment, supported by strategically placed screws to enhance structural robustness.
Extensive material testing is performed to identify the most suitable printing material, ensuring an optimal balance between durability and ease of printability. Additionally, a custom Printed Circuit Board (PCB) is designed to minimize wiring complexity, incorporating integrated sensors and standardized connectors. This approach not only resolves issues identified in the original design but also allows for future expansions and modular enhancements.

## 5.1. Mechanical Design

In the initial design, the robot consisted of multiple printable parts with a hollow interior, which compromised its robustness. The designated areas for components often resulted in loose fits, requiring hot glue to keep components securely in place. Additionally, the original design made accessing the battery pack and Raspberry Pi challenging once fully assembled. Moreover, the positioning of several components posed risks of accidental short-circuiting during everyday vibrations.

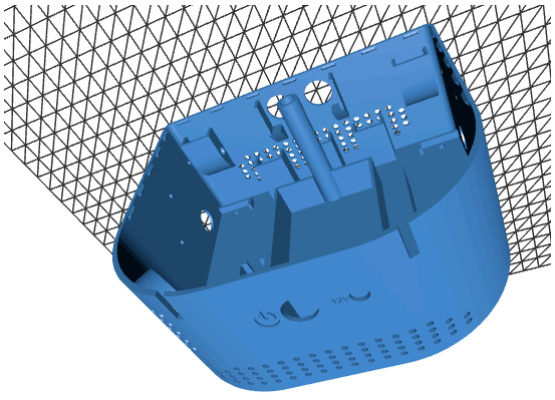
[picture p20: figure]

Figure 6. The main body of the original FOSSBot

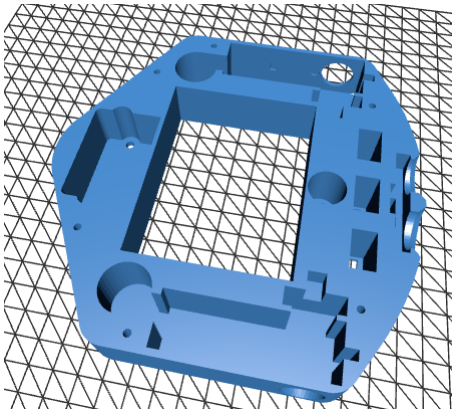
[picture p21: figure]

Figure 7. The new design of FOSSBot 2.0 lower body part, with the sockets for placing sensors and motors

In the new design, the robot's main body is divided into three parts. Each part is designed to avoid unnecessary hollow spaces by effectively utilizing 3D printing techniques, such as optimized infill, resulting in increased solidity and robustness. Each component now has clearly designated slots that ensure a tight fit, and the three main body parts are securely joined using screws placed in strategic locations. This "sandwich" approach ensures that all internal components remain firmly in place.

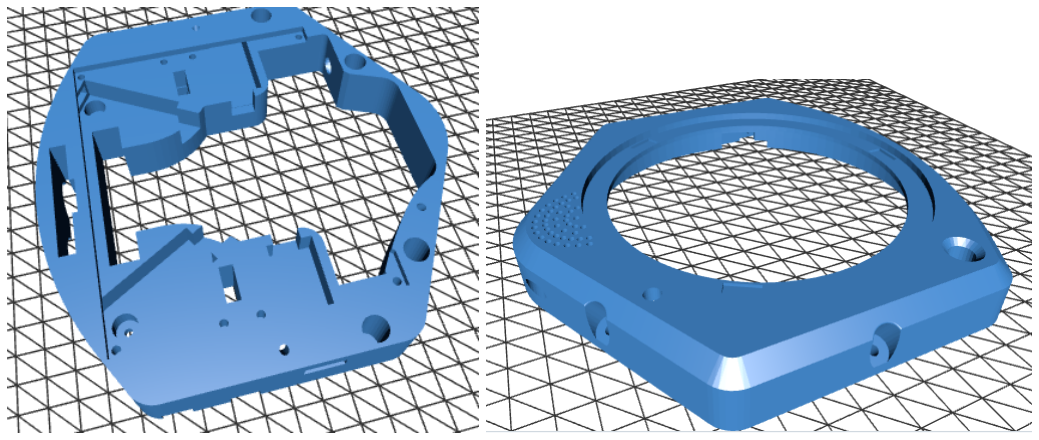
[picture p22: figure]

Figure 8. FOSSBot 2.0 middle and top body parts

Significant effort was made to safely placing power-related components. Specifically, high-voltage components are carefully positioned and isolated to prevent short circuits, even under extreme vibrations. The battery pack has been relocated to the robot's bottom and is covered by a specially designed access panel, allowing easy battery replacement without full disassembly. Additionally, the new design includes a multipurpose magnetic cover featuring a LEGO-compatible surface, providing convenient access to the robot's interior.

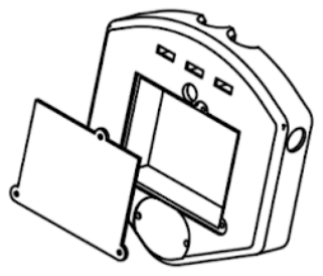
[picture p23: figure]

Figure 9. The new batteries slot in the lower part of the FOSSBot 2.0 body

The pen holder component has also been redesigned for improved durability and ease of use. Since we had reports from the users of the original FOSSBot that it easily breaks, the new pen holder is now more robust and removable, ensuring a tighter fit for pencils and allowing easy reprinting if damaged.

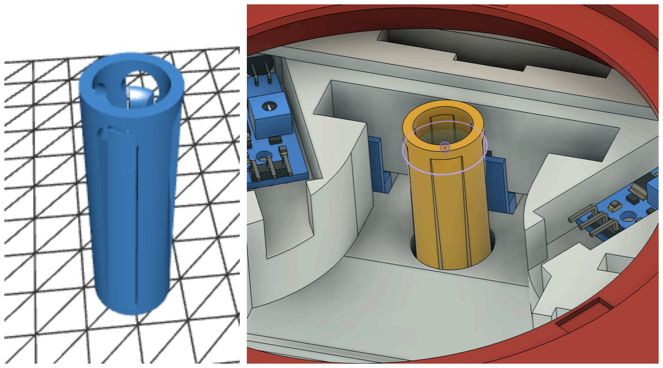
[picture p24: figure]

Figure 10. The newly designed, detachable pen holder

Lastly, the Raspberry Pi has been repositioned directly under the magnetic top cover, providing convenient access for camera or screen interface connections, as well as easy access to the micro-SD slot for future firmware updates.

Finally, after conducting research and testing, we determined that the optimal 3D printing material combining durability and minimal print failures is PET-G, commonly used in plastic water bottles. PET-G offers excellent durability, flexibility without cracking, resistance to UV light, sunlight exposure, and good thermal stability after printing. While the choice of printing material ultimately rests with the end-user, PET-G is highly recommended for optimal results.

The key elements of the new design can be summarized as follows:

- Three-part modular chassis for improved robustness.
- Intuitive slots and screw placement for easy assembly.
- Optimized 3D printing to reduce print failures.
- PET-G material selection for durability and flexibility.
- Battery pack repositioned with accessible cover for easy

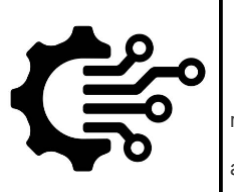
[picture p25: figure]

replacement.
- Magnetic LEGO-compatible top cover for easy internal access.
- Redesigned removable pen holder for enhanced durability and usability.
- Safe isolation of high-voltage components to avoid short circuits.

## 5.2. Electronics Design

In the new robot design, we introduced a custom PCB to simplify the assembly process significantly. In the original version, electronic components were connected using numerous wires, which often overwhelmed users. The large number of wires also made it challenging to follow instructions clearly, and any disconnections were difficult to troubleshoot.

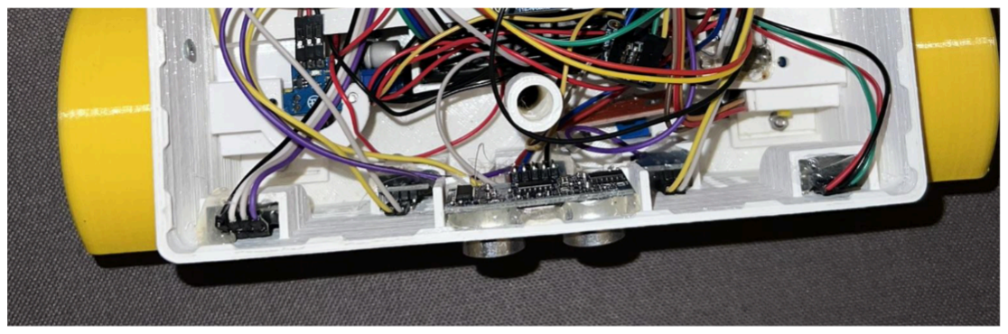
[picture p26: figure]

Figure 11. A part of the wiring of the original FOSSBot

The PCB that has been designed in terms of S.T.E.P.S. minimizes the need for multiple small PCBs that previously hosted simple components like LEDs or photoresistors. By integrating these components directly into the main PCB, we reduced wiring complexity and lowered overall costs. The PCB now utilizes JST connectors, creating a standardized and secure method for attaching components to the robot. Additionally, the PCB is specifically designed to allow easy access to the Raspberry Pi from the robot's top. This design enhances user convenience by facilitating connections to the Raspberry Pi camera and screen interfaces, enabling further sensor expansions.

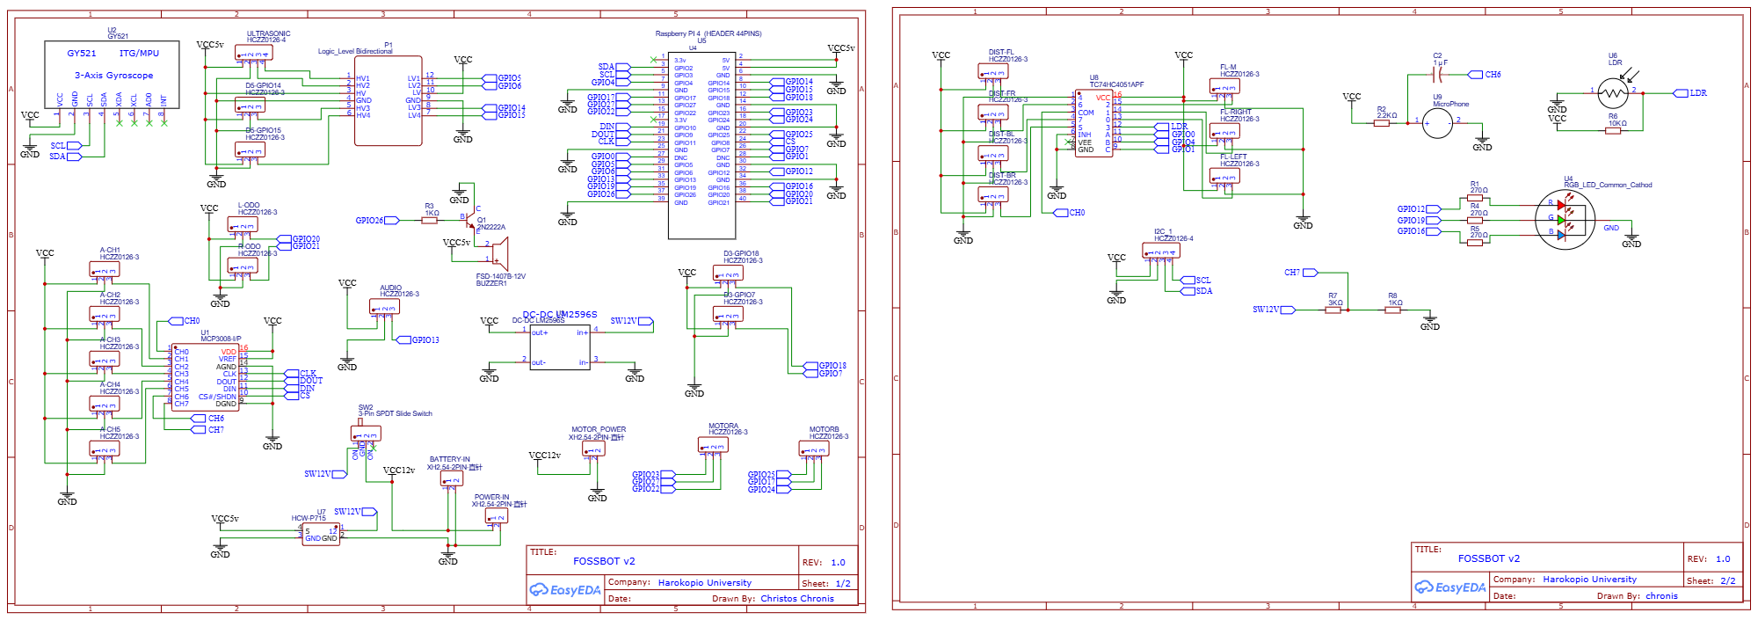
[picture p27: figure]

Figure 12. The schematics of the PCB of FOSSBot 2.0

The new PCB incorporates additional integrated components, such as a multiplexer, providing the robot with more digital and analog pins to accommodate a broader range of sensors. The I2C interface is exposed via a JST connector, allowing the easy connection of I2C-based electronic components like small LCD screens or PWM controllers. Furthermore, the robot now supports not only the original Li-Ion battery pack but also any 12V battery.
Integrated directly into the PCB are components such as a photoresistor, RGB LED, buzzer, noise sensor, battery sensor, and I2C port. It includes four digital component ports and five additional analog component ports for extra sensors, as well as four additional IR distance sensors for perimeter object detection. The Raspberry Pi interfaces for camera and screen access are clearly exposed for easy connectivity. The PCB retains compatibility with the original robot’s ultrasonic sensor, audio output, three IR distance sensors, and motor driver however, these components now connect via standardized JST connectors.

The key elements of the new PCB designs:

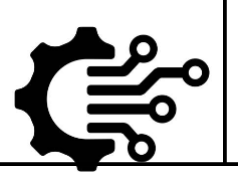
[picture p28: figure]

- Custom PCB to simplify assembly and reduce wiring complexity.
- Standardized | JST | connectors | for | reliable
component connections.
- Integrated multiplexer expanding available pins for additional sensors.

- Compatibility with various battery types (Li-Ion and 12V).
- Clearly exposed Raspberry Pi interfaces for easy camera/screen integration.
- Built-in sensors and components (photoresistor, RGB LED, buzzer, noise sensor, battery sensor).
- Expanded sensor support including additional IR distance sensors and I²C-based expansions.

## 5.3 Software Architecture and Connectivity

The software architecture of FOSSBot 2.0 has been significantly enhanced to improve usability, flexibility, and performance while maintaining compatibility with the existing main stack. These improvements focus on simplifying the user experience, extending functionality, and ensuring seamless integration between the simulation environment and the physical robot. Key updates include the removal of the Jupyter notebook option, the extension of the main robot control library, the addition of new Blockly blocks, the development of a browser-based CoppeliaSim plugin, and the implementation of thorough testing to ensure code portability.

Simplified Programming Interface
To make the platform more accessible to users with varying levels of programming expertise, the Jupyter notebook option has been removed. Instead, the focus has been placed on visual no-code programming using Blockly. This decision aligns with the goal of making FOSSBot 2.0 more user-friendly, particularly for educational settings where students may not have prior coding experience. The Blockly interface has been expanded with new blocks to support the additional sensors and components introduced in the updated hardware design. These blocks enable users to easily program advanced functionalities, such as object detection, sound recognition, and environmental monitoring, without writing a single line of code.

Extended Robot Control Library
The main robot control library has been extended to support the new sensor components integrated into the custom PCB, such as the photoresistor, RGB LED, buzzer, noise sensor, and additional IR distance sensors. This extension ensures that all hardware components are fully accessible through the software interface, enabling users to leverage the full capabilities of the robot. The library now includes pre-built functions for common tasks, such as reading sensor data, controlling motors, and managing I2C-based devices, reducing the complexity of programming and allowing users to focus on higher-level logic.

Browser-Based CoppeliaSim Plugin
To address the challenges of installing and using the CoppeliaSim robot simulation environment, a browser-based plugin has been developed. This plugin eliminates the need for complex local installations and ensures that users can access the simulation environment directly from their web browsers. The plugin is fully integrated with the Blockly programming interface, allowing users to test their code in a simulated environment before deploying it to the physical robot. This approach not only simplifies the setup process but also enhances the learning experience by providing immediate feedback and reducing the risk of errors when transitioning from simulation to real-world execution.

Enhanced Code Portability
A major focus of the software improvements has been ensuring the portability of code between the simulated environment and the actual robot. To achieve this, extensive testing has been conducted to validate that programs written for the simulation environment behave identically when executed on the physical robot. This testing includes edge cases, such as varying sensor inputs, motor control precision, and environmental conditions, to ensure robustness and reliability. As a result, users can confidently develop and test their programs in the simulation environment, knowing that they will perform as expected on the real robot.

Multilingual User Interface Support
To make FOSSBot 2.0 accessible to a global audience, the user interface (UI) now supports six languages: English, Spanish, French, German, Greek, and Italian. This multilingual support extends to all aspects of the software, including the Blockly programming interface, the CoppeliaSim plugin, and the robot control library documentation. The UI has been designed to dynamically switch between languages based on user preferences, ensuring a seamless experience for non-English speakers. This feature is particularly valuable in educational settings, where students and teachers may prefer to interact with the platform in their native language. The translation process involved collaboration with native speakers to ensure accuracy and cultural relevance, further enhancing the usability of the platform.

The key elements Software Architecture improvement are:

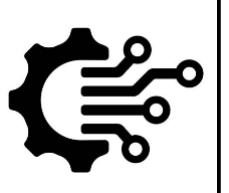
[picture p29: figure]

- Visual No-Code Programming: Exclusive use of Blockly for an intuitive and accessible programming experience.
- Extended Robot Control Library: Support for new sensors and components, with pre-built functions for common tasks.
- New Blockly Blocks: Addition of blocks for advanced functionalities, such as object detection and environmental monitoring.
- Browser-Based CoppeliaSim Plugin: Simplified access to the simulation environment via a web browser.
- Thorough Testing: Comprehensive validation of code portability between simulation and real-world execution.

- Multilingual UI Support: User interface available in six languages (English, Spanish, French, German, Greek, and Italian) to cater to a global audience.

These software architecture improvements ensure that FOSSBot 2.0 remains a versatile and user-friendly platform for robotics education, while also providing the tools and flexibility needed for more advanced applications. By streamlining the programming interface, extending hardware support, and enhancing simulation capabilities, the updated software architecture empowers users to explore the full potential of the FOSSBot platform.

# 6. Key Features and Innovations

## 6.1. Simplified Assembly Process

The assembly process of FOSSBot 2.0 has been designed to be intuitive and educational, making it suitable for users of all ages, including students and educators. The robot's 3D-printed parts are modular and feature predefined slots, ensuring that components fit securely without the need for additional tools or adhesives. This design not only simplifies the assembly process but also turns it into a hands-on learning activity, where users can understand the relationship between mechanical design and functionality. Additionally, the use of fewer materials and optimized 3D printing techniques has significantly reduced printing time and material waste, making the robot more environmentally friendly and cost-effective.
The introduction of a custom PCB board has further streamlined the assembly process by minimizing the number of cables required. In the previous version, the extensive wiring was a common source of confusion and errors during assembly. The new PCB integrates most electronic components and uses standardized JST connectors, reducing wiring complexity and making it easier for users to connect sensors, motors, and other components. This simplification ensures that even users with limited technical expertise can assemble the robot efficiently, fostering a sense of accomplishment and encouraging further exploration.

## 6.2. Enhanced Durability and Usability

FOSSBot 2.0 has been designed with durability and usability as key priorities. The 3D-printed plastic parts are now more robust, thanks to the use of optimized infill patterns and the recommended PET-G material, which offers excellent durability, flexibility, and resistance to wear and tear. Each printing material has been carefully evaluated to ensure it strikes the right balance between strength and ease of printing, making the robot suitable for long-term use in educational environments.
Moreover, the modular design of the robot ensures that sensors and electronic components can be easily detached and reused in other projects. This not only extends the lifespan of the components but also encourages creativity and experimentation. For example, students can repurpose the robot's sensors for other STEM projects, such as environmental monitoring or interactive art installations. This reusability aligns with the principles of sustainability and cost-effectiveness, making FOSSBot 2.0 a versatile tool for both learning and innovation.

## 6.3. Support for Multiple Programming Levels

FOSSBot 2.0 caters to users with varying levels of programming expertise by offering a modular programming environment with two modes: Kindergarten and Blockly. The Kindergarten mode is designed for young learners and provides a simple, icon-based interface that introduces basic programming concepts through playful interactions. The Blockly mode offers a visual, drag-and-drop programming interface, making it ideal for beginners and intermediate users who want to create more complex programs without writing code.
By supporting multiple programming levels and a no-code UI FOSSBot 2.0 ensures that it can grow with the user, providing a continuous learning pathway from basic concepts to advanced robotics programming.

## 6.4. Expandable and Customizable Modules

FOSSBot 2.0 is designed to be highly expandable and customizable, making it suitable for a wide range of educational applications and age groups. The robot's modular architecture allows educators to tailor its functionality to specific lessons or experiments. For example, additional sensors, such as temperature or humidity sensors, can be easily integrated to support science experiments, while actuators like servos can be added for more advanced robotics projects. This flexibility extends to the robot's software as well. The accompanying application can be customized to include specific programming challenges or educational content, making it adaptable to different curricula and learning objectives. Whether used in a primary school classroom or a university robotics lab, FOSSBot 2.0 can be configured to meet the needs of diverse educational settings, ensuring its relevance across multiple subjects and age groups.

## 6.5. Cost-Effective and Open-Source Design

One of the core principles of FOSSBot 2.0 is its commitment to being cost-effective and open-source. All design files, including 3D models, PCB schematics, and assembly instructions, are freely available online, allowing anyone to build, modify, and improve the robot. This open-source approach not only reduces the cost of ownership but also fosters a community of users who can share knowledge, collaborate on projects, and contribute to the platform's ongoing development.
In addition to the design files, detailed instructions on how to construct and program the robot are provided, ensuring that even users with limited technical expertise can get started quickly. If any electronic components break or need to be replaced, they can be easily sourced from online electronics or robotics stores, further reducing maintenance costs. By combining affordability with accessibility, FOSSBot 2.0 democratizes robotics education, making it available to schools, hobbyists, and educators worldwide.

# 7. Comparison with FOSSBot

FOSSBot 2.0 represents a significant evolution from its predecessor, incorporating design, educational, and usability improvements while maintaining its cost-effective and open-source principles. This section highlights the key differences between FOSSBot and FOSSBot 2.0, emphasizing the advancements that make the new version more durable, accessible, and versatile for educational purposes.

## 7.1. Design and Structural Improvements

FOSSBot 2.0 features a more modern and durable design compared to the original FOSSBot. The new modular design for its 3D-printed plastic components minimizes assembly time and simplifies maintenance. Each part is designed with predefined slots and screw placements, ensuring a secure fit and reducing the need for additional adhesives. This modularity not only makes the robot easier to assemble but also allows for quick disassembly and repair, which is particularly useful in educational settings.
Additionally, FOSSBot 2.0 has been optimized to reduce 3D printing time and material usage. The use of advanced infill patterns and the recommended PET-G material ensures that the robot is both lightweight and robust. The overall size of the robot has also been reduced, making it more compact and portable without compromising its functionality. These design improvements make FOSSBot 2.0 more user-friendly and suitable for a wider range of applications.

## 7.2. Enhanced Educational Features

FOSSBot 2.0 introduces several features that enhance its educational value. The platform now supports multiple programming levels, catering to users of all skill levels, from kindergarten students to advanced programmers. The modular programming environment includes three modes: Kindergarten (icon-based), Blockly (visual programming), and Monaco (text-based coding), ensuring that the robot can grow with the user’s skills.
The top panel of FOSSBot 2.0 is LEGO-compatible, allowing users to attach custom builds and expand the robot’s capabilities creatively. The integration of CoppeliaSim as a browser-based plugin provides a seamless simulation experience, enabling users to test their programs in a virtual environment before deploying them to the physical robot. Furthermore, the inclusion of I2C connectivity allows for the easy integration of additional sensors and peripherals, making the robot a versatile tool for teaching robotics, programming, and STEM concepts.

## 7.3. Usability and Accessibility Comparison

FOSSBot 2.0 significantly improves usability and accessibility compared to its predecessor. The integration of a Raspberry Pi as a web server enables users to control the robot remotely via a web interface, enhancing its flexibility in classroom settings. Wi-Fi connectivity has been introduced, allowing users to connect to the robot wirelessly, eliminating the need for physical connections and simplifying the setup process.
The new custom PCB integrates multiple circuits, reducing the number of cables and connections required. This not only simplifies assembly but also makes troubleshooting easier. The use of JST connectors ensures that sensors and components can be attached and replaced quickly, further enhancing the robot’s usability. Additionally, the top panel is now attached with magnets, providing easy access to internal components and making maintenance more straightforward.

## 7.4. Cost and Manufacturing Efficiency

FOSSBot 2.0 maintains the cost-effective and open-source principles of the original FOSSBot while introducing manufacturing efficiencies that reduce overall costs. The optimized 3D printing process minimizes material usage and printing time, lowering production costs. The custom PCB reduces the need for additional wiring and connectors, further cutting down on expenses. All design files, including 3D models, PCB schematics, and assembly instructions, remain freely available online, ensuring that the robot is accessible to a wide audience. The use of standardized electronic components means that replacements can be easily sourced from online stores, reducing long-term maintenance costs. These improvements make FOSSBot 2.0 an even more affordable and sustainable option for schools, educators, and hobbyists.

Table 1. Comparison between FOSSBot and FOSSBot 2.0

Feature | FOSSBot | FOSSBot 2.0
Design | Single-part chassis | Modular 3-part chassis
Assembly | Complex wiring, hot glue needed | Simplified wiring, screw-based assembly
3D Printing Time (with the default printing speed) | 59 hours | Reduced to 51 hours
Material Usage | 380 gr | Reduced to 343 gr
Size | Larger | Smaller and more compact
Programming Levels | Limited | 3 modes (Kindergarten, Blockly, Monaco)
LEGO Compatibility | No | Yes

Simulation | Local CoppeliaSim installation | Browser-based CoppeliaSim plugin
Connectivity | Wired | Wi-Fi and web server integration
PCB Design | Multiple small PCBs | Single custom PCB with JST connectors
Top Panel Access | Screw-based | Magnetic attachment
Cost | Low | Even lower due to manufacturing optimizations
Open-Source Availability | Yes | Yes

FOSSBot 2.0 builds on the strengths of its predecessor while addressing its limitations, resulting in a more durable, accessible, and versatile platform for robotics education. These improvements ensure that FOSSBot 2.0 remains a cost-effective and open-source solution for educators and learners worldwide.

# 8. Conclusion

FOSSBot 2.0 marks a transformative advancement in educational robotics, building on the foundation of its predecessor while introducing innovative features that enhance usability, durability, and accessibility. This concluding section summarizes the key achievements of FOSSBot 2.0, highlights its potential impact on educational robotics, and issues a call to action for educators and developers to adopt and contribute to this open-source platform.

## 8.1. Summary of Achievements

FOSSBot 2.0 has achieved significant milestones that set it apart as a leading tool for robotics education. The robot’s modular 3D-printed design simplifies assembly and maintenance, while optimized printing techniques reduce material usage and production time. The introduction of a custom PCB minimizes wiring complexity, enhances reliability, and supports a wide range of sensors and components, making the robot more user-friendly and versatile.

The platform’s support for multiple programming levels—Kindergarten (icon-based), Blockly (visual programming), and Monaco (text-based coding)—ensures that it caters to users of all skill levels, from young learners to advanced programmers. The integration of a browser-based CoppeliaSim plugin and Wi-Fi connectivity enables seamless transitions between simulation and real-world execution, enhancing the learning experience. Additionally, the multilingual user interface (supporting six languages) and LEGO-compatible top panel expand its appeal and adaptability in diverse educational settings.

FOSSBot 2.0 also emphasizes sustainability and reusability, with durable 3D-printed parts and components that can be repurposed for other projects. Its open-source design, with all files and instructions freely available online, ensures that the robot remains accessible and affordable for schools, educators, and hobbyists worldwide.

## 8.2. Impact on Educational Robotics

FOSSBot 2.0 has the potential to revolutionize robotics education by providing a versatile, cost-effective, and accessible platform for teaching STEM concepts. Its modular and expandable design makes it suitable for a wide range of applications, from introductory programming exercises to advanced robotics projects. By supporting multiple programming levels and offering a seamless simulation environment, FOSSBot 2.0 empowers students to learn at their own pace, experiment with new ideas, and develop critical problem-solving skills.

The robot’s emphasis on durability and reusability ensures that it can withstand the demands of classroom use while promoting sustainability. Its open-source nature fosters a collaborative community of educators, developers, and students who can share knowledge, develop new features, and adapt the platform to meet evolving educational needs. By lowering the barriers to entry for robotics education, FOSSBot 2.0 has the potential to inspire the next generation of innovators, engineers, and scientists.

## 8.3. Call to Action for Educators and Developers

FOSSBot 2.0 is more than just a robot—it is a powerful tool for empowering learners and fostering a deeper understanding of robotics, programming, and STEM concepts. Educators are encouraged to integrate FOSSBot 2.0 into their curricula, leveraging its versatility to teach a wide range of subjects, from computer science and engineering to environmental science and creative design. By providing students with hands-on experience in robotics, educators can inspire curiosity, creativity, and a passion for learning.

Developers and hobbyists are invited to contribute to the ongoing development of FOSSBot 2.0. Whether by designing new sensors, creating additional Blockly blocks, improving the simulation environment, or translating the user interface into more languages, there are countless opportunities to enhance the platform and expand its capabilities. The open-source nature of FOSSBot 2.0 ensures that it will continue to evolve, driven by the collective efforts of a global community.

In conclusion, FOSSBot 2.0 represents a significant step forward in making robotics education accessible, engaging, and impactful. By embracing this platform, educators and developers can play a pivotal role in shaping the future of STEM education and inspiring the innovators of tomorrow. Together, we can unlock the full potential of robotics as a tool for learning, creativity, and innovation.

# References

Chronis, C., & Varlamis, I. (2022). Fossbot: An open source and open design educational robot. Electronics, 11(16), 2606.
Mamatnabiyev, Z., Chronis, C., Varlamis, I., Himeur, Y., & Zhaparov, M. (2024). A holistic approach to use educational robots for supporting computer science courses. Computers, 13(4), 102.
M. A. Merino-Fernández, A. I. Cuesta, A. Alonso-Centeno, L. A. Mínguez, I. Varlamis, C. Sofianopoulou, S. Aykuş, Ch. Rousoulioti, A. Vrantzas, I. Siakavaras, G. Papaioannou, N. Pischos, K. Burcke, T. Angelopoulos, and J. Ortiz-Revilla. Theoretical and practical coherence of integrated STEM education and educational robotics: review and analysis of good practices in Europe. In S. Papadakis & G. Lampropoulos (Eds.), Social Robots and Artificial Intelligence in Education: Integrating AI in K-12 and Higher Education. Palgrave Macmillan.

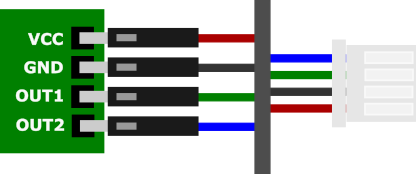
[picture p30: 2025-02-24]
images/c_gen_4png.png

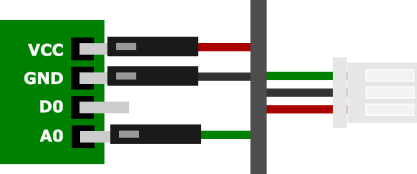
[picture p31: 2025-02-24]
images/c_ir.png

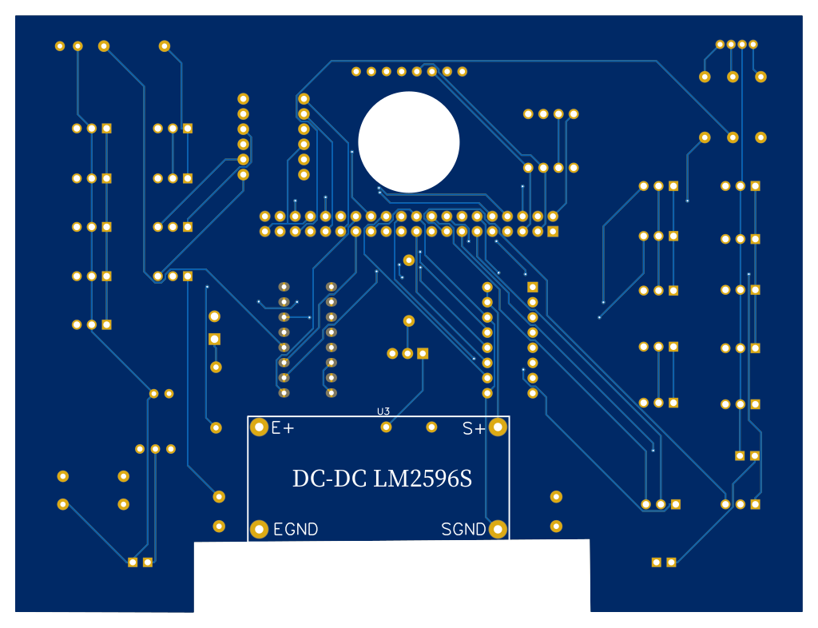
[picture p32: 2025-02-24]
images/circuit_back.png

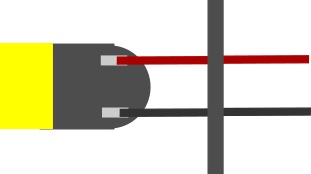
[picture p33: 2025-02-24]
images/c_motor.png

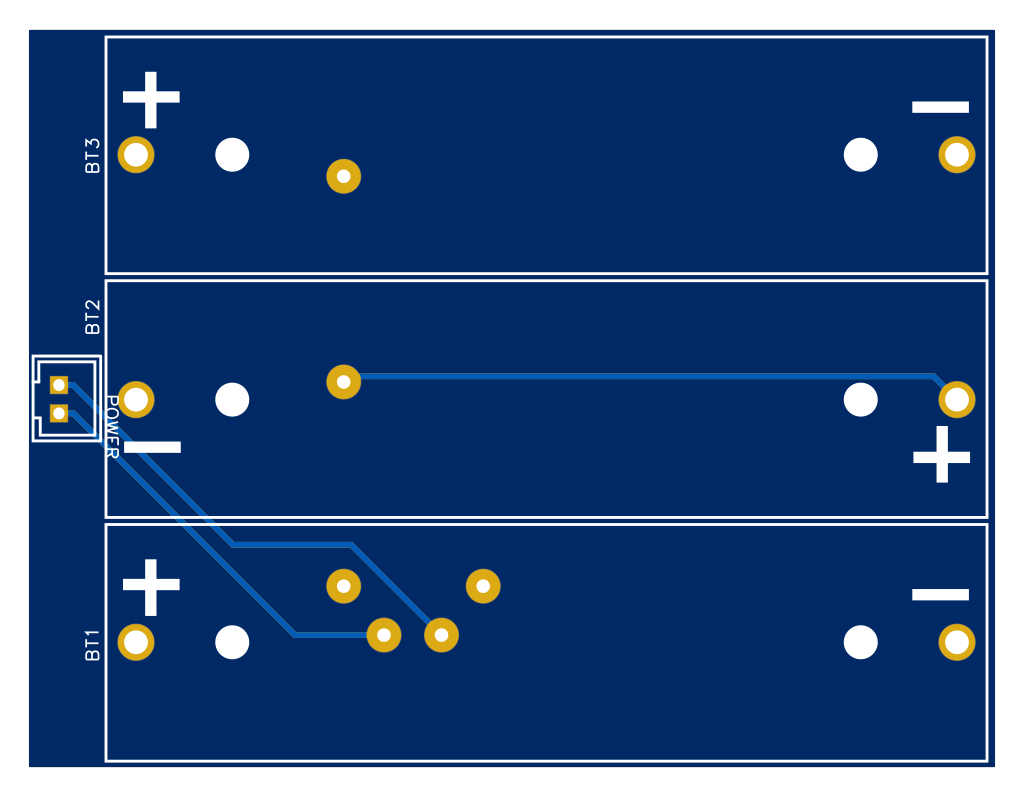
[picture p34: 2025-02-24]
images/circuit_battery_front.png

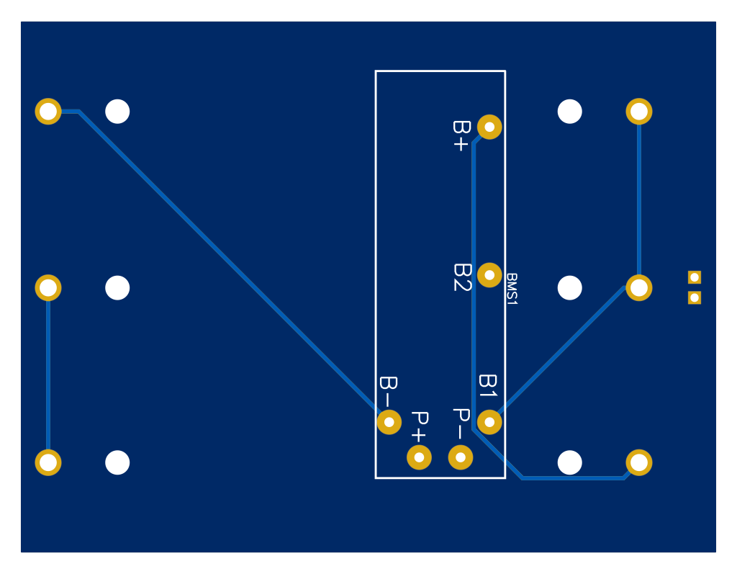
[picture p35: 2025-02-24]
images/circuit_battery_back.png

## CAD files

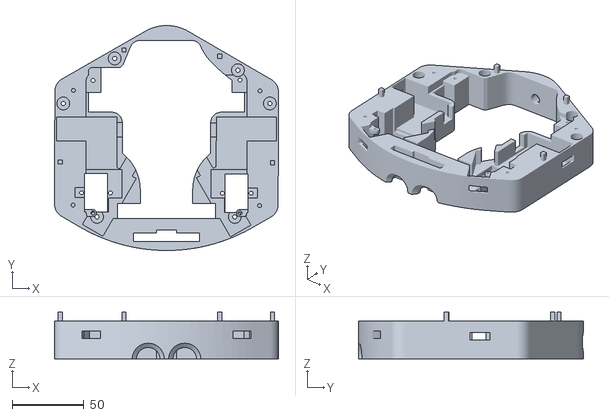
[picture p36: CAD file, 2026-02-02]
stl/b2_p_f.stl
156.1 x 156.8 x 32.5

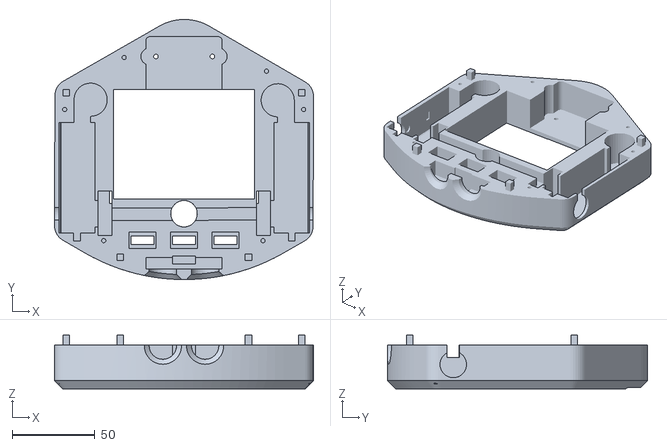
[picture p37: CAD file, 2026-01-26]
stl/b1_p_f.stl
156.1 x 156.8 x 32.5

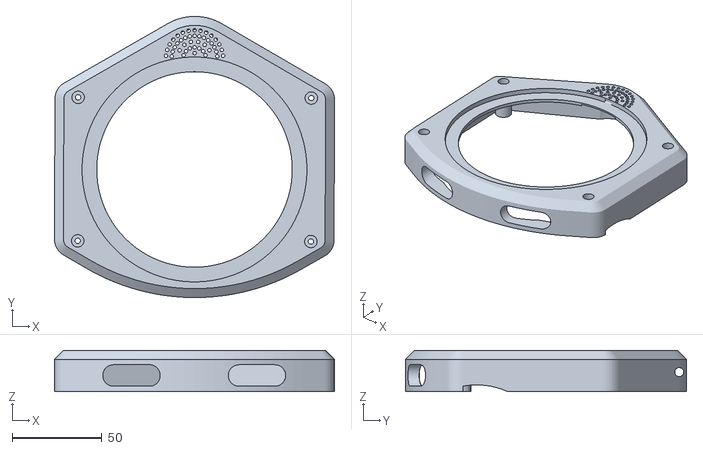
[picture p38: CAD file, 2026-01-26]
stl/b3_p_f.stl
156.1 x 156.8 x 23.0

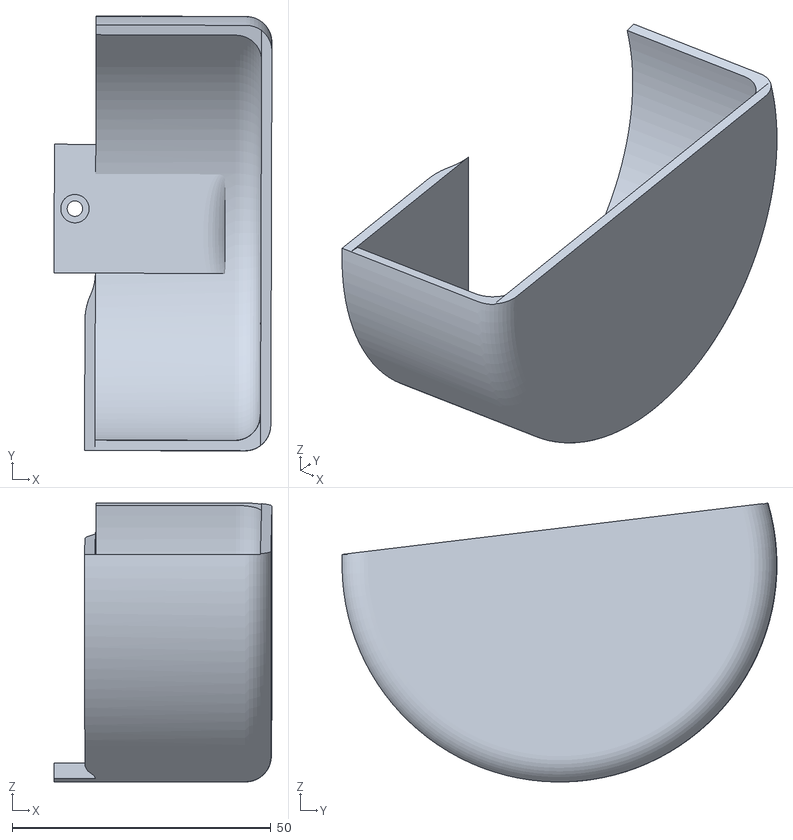
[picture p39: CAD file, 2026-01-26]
stl/right_fender.stl
42.1 x 84.1 x 53.9

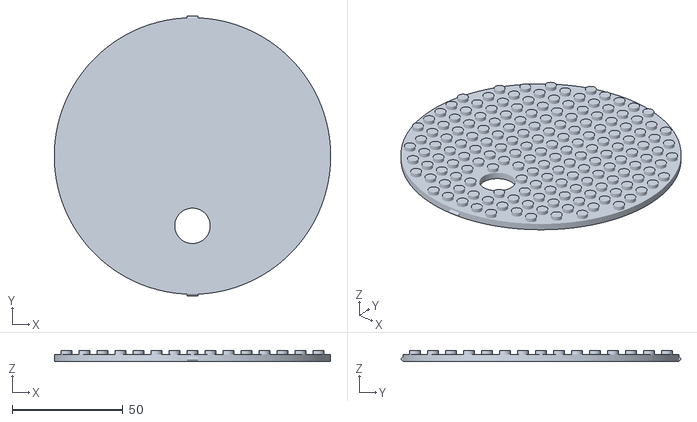
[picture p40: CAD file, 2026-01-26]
stl/lego_top.stl
124.7 x 126.3 x 4.75

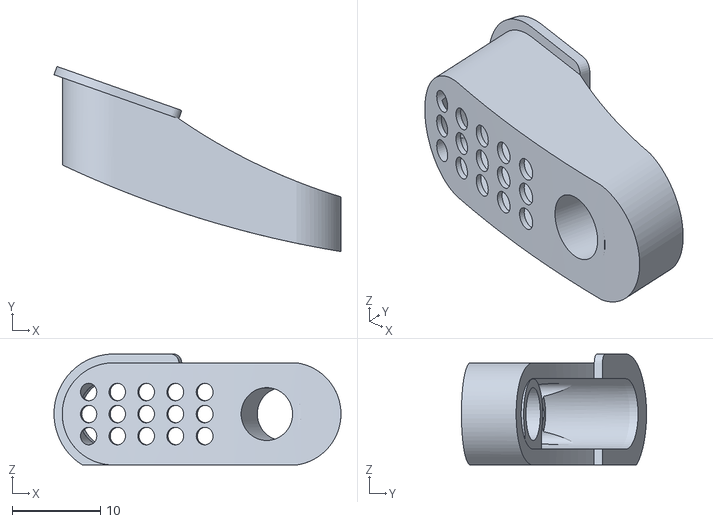
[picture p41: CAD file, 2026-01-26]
stl/right_eye.stl
32.6 x 21.0 x 12.6

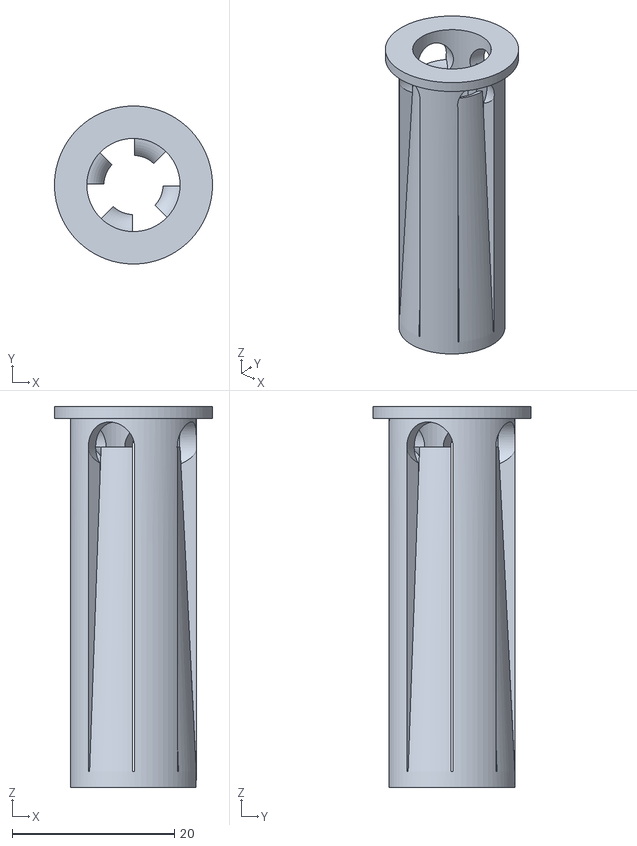
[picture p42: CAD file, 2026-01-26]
stl/pen_holder.stl
19.5 x 19.5 x 47.0

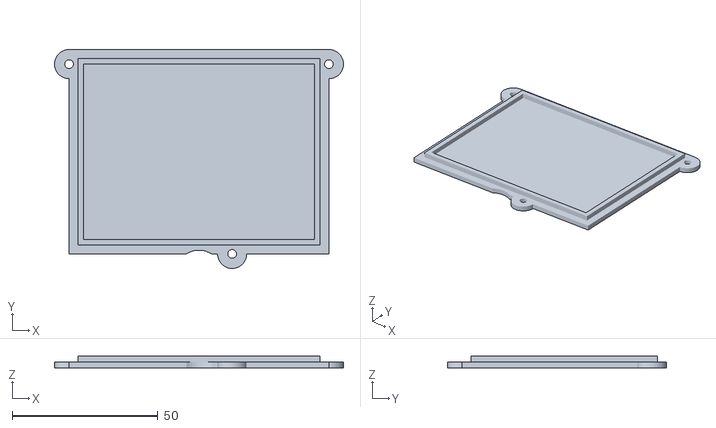
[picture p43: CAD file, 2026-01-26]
stl/batterycover.stl
99.0 x 75.0 x 4.00

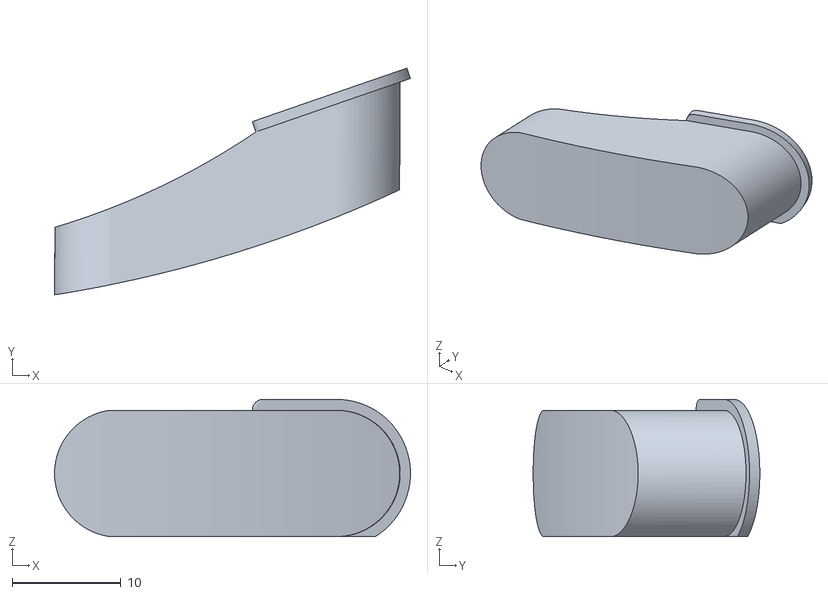
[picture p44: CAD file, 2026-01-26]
stl/left_eye.stl
32.7 x 20.8 x 12.6

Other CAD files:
stl/left_fender.stl

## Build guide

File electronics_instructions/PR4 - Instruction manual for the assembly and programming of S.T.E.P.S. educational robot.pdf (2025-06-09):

# FOSSBot 2.0 Instruction Manual

## Table of contents

1. Introduction | 3
2. Printing instructions | 4
2.1 List of plastic parts and files downloading instructions | 4
2.2. Preparing the printer | 4
2.3 Plastic part visuals | 5
2.3.1. Bottom Base | 5
2.3.2. Middle Base | 6
2.3.3. Top Base | 6
2.3.3. Top Cover | 6
2.3.3. Battery Cover | 7
2.3.3. Spoilers | 7
2.3.3. Pen Holder | 7
2.4 Printing times | 8
3. Electronics and wiring | 9
3.1. List of electronic parts | 9
3.2. The PCB boards | 16
3.2.1 Main PCB | 16
3.2.2 Battery pack PCB | 28
3.3 Wiring | 31
4. Assembly Instructions | 34
5. Setting up and running | 45
Download the image file | 45
Installing the image | 45
Configuring the WIFI credentials | 46
Attach microSD card to FOSSBot | 46
6. Basic programming | 48
Examples | 49
Obstacle avoidance | 49
Line following | 50
Light detection | 51
7. Troubleshooting tips | 53
8. Glossary | 54

## 1. Introduction

FOSSBot is an open-source and open design DIY educational robot¹
that has been
designed to help students, educators, and STEM enthusiasts improve the educational process with the use of programmable robots.

In terms of the S.T.E.P.S. project, the FOSSBot has been redesigned and improved to cover the increasing needs of educators, offering an innovative STEM teaching tool focused on making robotics and STEM education accessible to a wider audience. With the current robot, the project aims to overcome barriers in STEM learning by providing affordable, hands-on tools and resources designed to support educators and engage students.

Through the redesigned FOSSBot the S.T.E.P.S. project attempts to democratize and enhance access to STEM education by leveraging affordable, open-source technology and digital learning resources.

## About the Manual

The manual for the S.T.E.P.S. project is designed for pre-service and in-service secondary school teachers and trainers who wish to incorporate STEM and robotics into their educational practice, even if they have little or no prior experience with these technologies.

Its structure includes detailed instructions on how to:

- download and print the plastic parts of the robot
- buy and assemble the list of electronics and other non-printable parts.
- connect and operate the robot
- program the robot

By offering accessible guidance, this resource aims to increase teachers' confidence and capacity to use the robot in practice.

1 https://github.com/eellak/fossbot

## 2. Printing instructions

2.1 List of plastic parts and files downloading instructions
The first step in preparing the new robot is to download all the designs of the 3D printable plastic parts, which are freely available on Github: https://github.com/chronis10/fossbot-hardware/tree/fossbot-v2

Make sure to download and print the following parts:
1. Bottom base - bbase.stl (https://github.com/chronis10/fossbot-hardware/blob/fossbot-v2/stl/bbase.stl)
2. Battery cover - battery_cover.stl (https://github.com/chronis10/fossbot-hardware/blob/fossbot-v2/stl/battery_cover.stl)
3. Left wheel spoiler - spoiler_l.stl (https://github.com/chronis10/fossbot-hardware/blob/fossbot-v2/stl/spoiler_l.stl)
4. Right wheel - spoiler_r.stl (https://github.com/chronis10/fossbot-hardware/blob/fossbot-v2/stl/spoiler_r.stl)
5. MIddle base - mbase.stl (https://github.com/chronis10/fossbot-hardware/blob/fossbot-v2/stl/mbase.stl)
6. Top base - tbase.stl (https://github.com/chronis10/fossbot-hardware/blob/fossbot-v2/stl/tbase.stl)
7. Top cover - tcover.stl (https://github.com/chronis10/fossbot-hardware/blob/fossbot-v2/stl/tcover.stl)
8. Pen holder - pen_holder.stl (https://github.com/chronis10/fossbot-hardware/blob/fossbot-v2/stl/pen_holder.stl)

Download the files
All the parts are stored as .stl files in the stl folder and are available for download. The .stl file represents geometric data of 3D object models as triangular meshes and contains information about the coordinates of each triangle and the direction of each surface.

Changing the designs (optional)
The .stl file is one of the most popular files for 3D printing objects and can be used in design and engineering programs such as AutoCAD, SolidWorks, Blender, Tinkercad. If you want to preview or modify any of the 3D printable parts of the robot, you can use any of the above software available for your OS and customize them.

Slicing and preparing for printing
The next step is to import the .stl files into a suitable program for slicing, such as the CURA software. The software takes the 3D model and converts it into G-code, which is the format needed to print with a 3D printer.
2.2. Preparing the printer

Before the printing of the plastic parts begins, the printing material (plastic thread) needs to be inserted into the 3D printer. We recommend the use of PETG plastic for printing because of each balance between low cost and durability, but any other suitable material can be chosen.

Next, you must warm up the printer. The temperature of the printing nozzle and the temperature of the bed, i.e. the surface on which the object is going to be printed, must be set. The temperatures differ for each printing material as well as for different types of printing surfaces.

Material | Nozzle Temperatur e (°C)

Bed
Temperature
(°C)

Notes

PLA | 190–220 | 50–70 | Easy to print, low warping, no
heated | bed | required | (but
recommended).
PETG (Suggested) | 230–250 | 70–90 | Strong and durable, requires
good bed adhesion.
ABS | 230–250 | 90–110 | Prone to warping; enclosed
printer recommended.

Table 1. Recommended Printing Temperatures for Different Materials

Notes for PETG Printing:
- Nozzle Temperature: PETG typically prints best between 230–250°C. Too low, and it won’t adhere well; too high, and it may string or ooze.
- Bed Temperature: A bed temperature of 70–90°C is ideal for PETG. It adheres well to surfaces like PEI, glass with glue stick, or blue painter’s tape.
- Cooling Fan: Use partial fan speed (20–50%) to reduce warping and improve layer adhesion.
- Adhesion: PETG can stick too well to some surfaces, so consider using a release agent (e.g., glue stick) to prevent damage to the build plate.

2.3 Plastic part visuals

The new designs and a brief description of them follows:

2.3.1. Bottom Base
The bottom base houses the motors, odometers, ultrasonic distance sensors, floor IR distance sensors, batteries, and the motor driving circuit.

Figure 1. Bottom base of FOSSBot 2.0

2.3.2. Middle Base
The middle base houses IR distance sensors and also provides a surface for attaching the main PCB.

Figure 2. Middle base of FOSSBot 2.0

2.3.3. Top Base
The top base of the robot houses the speaker, light sensor, and LED. It also stabilizes the assembly of the robot, which is attached to the middle base.

Figure 3. Top base of FOSSBot 2.0

2.3.3. Top Cover
A magnetically attached top cover with a Lego-compatible surface. It allows easy access to the internal components of the robot and provides a convenient way to attach the pen holder component.

Figure 4. Top cover of FOSSBot 2.0

2.3.3. Battery Cover
The battery cover protects the battery from accidental removal. Additionally, this cover allows for easy access and replacement of the batteries when disposable batteries are used, accessible from the bottom of the robot.

Figure 5. Battery cover of FOSSBot 2.0

2.3.3. Spoilers
Protective covers for the wheels to prevent detachment due to unexpected crashes.

Figure 6. Spoilers of FOSSBot 2.0

2.3.3. Pen Holder

A special removable component is designed for attaching a pen to the robot. This component securely holds a pen and positions it at the bottom of the robot, enabling the robot to function as a plotter.

Figure 7. Pen holder of FOSSBot 2.0

2.4 Printing times

Each plastic part needs to be printed separately. Please refer to the following table for the estimated printing time of each part. The printing time and material specifications are for reference only, based on the default Cura settings with 10% infill for the Ender 3 Pro. You should adjust the settings to suit your printer best. By modifying the printing speed and infill density, you may achieve a faster print time while using less material.

Plastic robot part | Printing time (hours) | Material in grams | Support
Battery Cover | 1:53 | 15 | No
Bottom Base | 14:19 | 98 | Everywhere
Middle Base | 12:35 | 86 | Everywhere
Top Base | 8:40 | 59 | Everywhere
Left Spoiler | 3:50 | 25 | Touching build plate
Right Spoiler | 3:50 | 25 | Touching build plate
Lego top | 4:55 | 31 | Everywhere
Pen holder | 1:00 | 4 | No

Table 2. Estimated Printing Times and Material Usage for Robot Parts

## 3. Electronics and wiring

FOSSBot falls into the DIY (Do It Yourself) category, designed to be easily built by anyone beyond its original creators. Its assembly and disassembly can serve as an educational activity, making it an engaging learning tool in the classroom. This is possible since FOSSBot is made of electronic parts that are low cost and easily widely available while the plastic parts are printable. Therefore, they can be replaced easily in case a component is defective or it wears out.

3.1. List of electronic parts
The following list contains the electronic and non-printable parts that will be needed for the robot assembly:
Part Name | Photo | Quantity | Link
Rubber Wheel 66x26mm - Yellow | | 2 | https://grobotronics.com/rubber-wheel-66x26mm-yellow.html?sl=en&srsltid=AfmBOopd5-3DW47tWf BmrnNKnbCVc0dmFRVu bhED6B-bAPUGSDl1W6 jq (https://grobotronics.com/rubber-wheel-66x26mm-yellow.html?sl=en)
DC Gear Motor TT - 120 RPM (Metal Dual Shaft) | | 2 | https://botland.store/geared-dc-angle-motors/1601 6-dc-motor-with-148-gea r-3-6v-with-double-sided-shaft-200rpm-590442234 4078.html (https://botland.store/geared-dc-angle-motors/16016-dc-motor-with-148-gear-3-6v-with-double-sided-shaft-200rpm-5904422344078.html)
Coded Disc Encoder | | 2 | https://grobotronics.com/plastic-encoder-24mm.ht ml (https://grobotronics.com/plastic-encoder-24mm.html)
Dual Motor Driver Module L298N | | 1 | https://botland.store/motor-drivers-modules/3164-l298n-two-channel-motor -controller-12v-2a-59044 22359317.html (https://botland.store/motor-drivers-modules/3164-l298n-two-channel-motor-controller-12v-2a-5904422359317.html)

P h o t o In t e r r u p t e r S e n s o r | 2 | h t t p s:// b o tla n d.s t o r e / s e n s o r s -o d bicio w e / 8 8 3 4 -p h o t o -in t e r r u p t e r -s e n s o r -s p e e d -m e a s u rin g --5 9 0 4 4 2 2 3 6 6 2 9 2.h t
| 1 | https://botland.stor ml (https://botland.store/sensors-odbiciowe/8834-photo-interrupter-sensor-speed-measuring--5904422366292.html) MCP3008 - 10bit 8 channel ADC SPI e / c o n v e r t e r s / 2 3 5 8 -c o n v e r t e r -a d c -m c p 3 0 0 8 -1 0 -bit -8 -c h a n n el-dip -5 9 0 4 4 2 2 3 6 2 0 8
9. (https://botland.store/converters/2358-converter-adc-mcp3008-10-bit-8-channel-dip-5904422362089.html) html microSDHC 32GB | 1 | https://botland.store/micr osd-sd-cards/17091-san disk-memory-card-micro sd-32gb-80mbs-class-10 -raspberry-pi-os-590335 1247771.html DC-DC Step-Down 5.2V 5A | 1 | https://grobotronics.com/ dc-dc-converter-step-do wn-9-36v-5a.html DC-DC Converter Step-Down 5-35V 2A | 1 | https://grobotronics.com/ dc-dc-step-down-1.3-35v -3a.html?sl=en&srsltid=A fmBOooySa2M_pm3gMn fCiPTf9evSP-bVhUgBf6 OUDEJC7e1g8NO00lHX 9w Li-ion Battery Charger Protection Module 3S 10A | 1 | https://grobotronics.com/l i-ion-battery-charger-prot ection-module-3s-10a.ht ml

B

a

t

t

e

r

y

Li-io

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
s://

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
-lit

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
- (https://grobotronics.com/battery-lithium-18650-3.6v-3400mah-8a-samsung-inr18650-35e.html) inr18650-35e.html Battery holder 18650 | 3 | https://botland.store/batt ery-holders/16516-cell-h older-for-1x-18650-batter y-without-wires-5904422 344597.html Ultrasonic Distance Sensor HC-SR04 | 1 | https://botland.store/ultra sonic-distance-sensors/1 6257-ultrasonic-distance- sensor-hc-sr04-2-400cm- sparkfun-sleep-15569-59 04422378097.html IMU - MPU6050 (Accelerometer and Gyroscope) | 1 | https://grobotronics.com/ gy-521-mpu6050-3-axis- gyroscope-and-accelero meter-imu.html WAVESHARE IR proximity sensor with analog | 7 | https://grobotronics.com/ waveshare-infrared-proxi mity-sensor.html?gad_so urce=1&gclid=CjwKCAiA t4C-BhBcEiwA8Kp0CRlj uPmuZBYgBn4VrRwHzf NAGdLIiWcvREXeuI1YG BmSbw_Q06OxRBoCqz wQAvD_BwE

B

all C

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
al 1

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
s://

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
all-

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
m. (https://grobotronics.com/ball-caster-metal-12mm.html) html

Power supply 12V 5A -Output 5.5x2.1 SN-12D500 | 1 | https://grobotronics.com/power-supply-12v-5a-out put-5.5x2.1-sn-12d500.ht ml (https://grobotronics.com/power-supply-12v-5a-output-5.5x2.1-sn-12d500.html)
DC Power Jack 5.5x2.1 -Plastic | 1 | https://grobotronics.com/dc-power-jack-5.5x2.1-pl astic-el.html (https://grobotronics.com/dc-power-jack-5.5x2.1-plastic-el.html)
Transistor 2N2222A | 1 | https://botland.store/npn-transistors/18995-bipolar -transistor-npn-2n2222a-st-5pcs-5904422357931. html (https://botland.store/npn-transistors/18995-bipolar-transistor-npn-2n2222a-st-5pcs-5904422357931.html)
JST 4-pin female-to-female jumper pins | 2 | https://grobotronics.com/j umper-wire-jst-xh-to-sep arate-dupont.html?variati on_id=17936 (https://grobotronics.com/jumper-wire-jst-xh-to-separate-dupont.html?variation_id=17936)
JST 3-pin female-to-female jumper pins | 21 | https://grobotronics.com/j umper-wire-jst-xh-to-sep arate-dupont.html?variati on_id=17935 (https://grobotronics.com/jumper-wire-jst-xh-to-separate-dupont.html?variation_id=17935)

J S T 2 -pin f e m ale -t o -f e m ale j u m p e r pin s | 3 | h t t p s:// g r o b o t r o nic s.c o m /j u m p e r -wir e -j s t -x h -t o -s e p a r a t e -d u p o n t.h t ml? v a ria ti (https://grobotronics.com/jumper-wire-jst-xh-to-separate-dupont.html?variation_id=17934) on_id=17934
J S T X H C o n e c t o r 4 -Pin M ale 2.5 m m | 2 | h t t p s:// g r o b o t r o nic s.c o m /j s t -x h -c o n e c t o r -4 -pin -m
al (https://grobotronics.com/jst-xh-conector-4-pin-male-2.5mm.html) e-2.5mm.html JST XH Conector 3-Pin Male 2.5mm | 21 | https://grobotronics.com/j st-xh-conector-3-pin-mal e-2.5mm.html JST XH Conector 2-Pin Male 2.5mm | 3 | https://grobotronics.com/j st-xh-conector-2-pin-mal e-2.5mm.html On/Off Switch PCB 3pin SPDT Switch | 1 | https://ampere-electronic s.com/product/on-off-swit ch-pcb-3pin-spdt-switch/ ?srsltid=AfmBOoqiCXJJJ -AAeio8zfw4rX5ipF6zHL DEUZYFuHeTMvZXiLmq Z0Wo Raspberry Pi 2 Zero W | 1 | https://botland.store/rpi-z ero-modules-and-kits/20 347-raspberry-pi-zero-2- w-512mb-ram-wifi-bt-42- 5056561800004.html 10K Resistor | 1 | https://www.digikey.gr/en /products/detail/yageo/C FR-25JR-52-10K/11998

3K Resistor | 1 | https://www.digikey.gr/en/products/detail/stackpole-electronics-inc/CF14JT3K00/1741418 (https://www.digikey.gr/en/products/detail/stackpole-electronics-inc/CF14JT3K00/1741418)
2.2K Resistor | 1 | https://www.digikey.gr/en/products/detail/stackpole-electronics-inc/CF14JT2K20/1741321 (https://www.digikey.gr/en/products/detail/stackpole-electronics-inc/CF14JT2K20/1741321)
1K Resistor | 2 | https://www.digikey.gr/en/products/detail/stackpole-electronics-inc/CF14JT1K00/1741314 (https://www.digikey.gr/en/products/detail/stackpole-electronics-inc/CF14JT1K00/1741314)
270Ω Resistor | 3 | https://www.digikey.gr/en/products/detail/yageo/CFR-25JR-52-270R/11960 (https://www.digikey.gr/en/products/detail/yageo/CFR-25JR-52-270R/11960)
Bolt M3- L14mm | 12 | https://www.digikey.gr/en/products/detail/apm-hexseal/RM3X12MM-2701/2 063201 (https://www.digikey.gr/en/products/detail/apm-hexseal/RM3X12MM-2701/2063201)
Loudspeaker 2W 8Ω | 1 | https://www.digikey.gr/en/products/detail/same-sky-formerly-cui-devices/CLS0361-L152/1630878 (https://www.digikey.gr/en/products/detail/same-sky-formerly-cui-devices/CLS0361-L152/1630878)
Mono 2.5W Class D Audio Amplifier -PAM8302 | 1 | https://botland.store/mp3-wav-ogg-midi-players/63 81-mono-25w-class-d-au dio-amplifier-pam8302-a dafruit-2130-5904422348 (https://botland.store/mp3-wav-ogg-midi-players/6381-mono-25w-class-d-audio-amplifier-pam8302-adafruit-2130-5904422348960.html)

| | 960.html (https://botland.store/mp3-wav-ogg-midi-players/6381-mono-25w-class-d-audio-amplifier-pam8302-adafruit-2130-5904422348960.html)
4 Channels Bidirectional logic bit converter | 1 | https://botland.store/voltage-converters/6117-4-ch annel-logic-level-convert er-5904422365189.html (https://botland.store/voltage-converters/6117-4-channel-logic-level-converter-5904422365189.html)
Photoresistor (LDR) | 1 | https://www.digikey.gr/en/products/detail/advanced-photonix/PDV-P8103/4 80610 (https://www.digikey.gr/en/products/detail/advanced-photonix/PDV-P8103/480610)
Electrolytic Capacitors -1uF/50V | 1 | https://www.digikey.gr/en/products/detail/kemet/ESK105M050AC3AA/308 3011 (https://www.digikey.gr/en/products/detail/kemet/ESK105M050AC3AA/3083011)
Raspberry PI HEADER 44PINS | 1 | https://www.digikey.gr/en/products/detail/samtec-inc/SSW-122-02-S-D-LL/6694399 (https://www.digikey.gr/en/products/detail/samtec-inc/SSW-122-02-S-D-LL/6694399)
Microphone capsule | 1 | https://www.digikey.gr/en/products/detail/same-sky-formerly-cui-devices/CMA-4544PF-W/1869981 (http://www.digikey.gr/en/products/detail/same-sky-formerly-cui-devices/CMA-4544PF-W/1869981)
RGB LED Common Cathode | 1 | https://www.digikey.gr/en/products/detail/kingbright/WP154A4SUREQBFZGC/3084119 (https://www.digikey.gr/en/products/detail/kingbright/WP154A4SUREQBFZGC/3084119)

Buzzer 12V | 1 | https://www.digikey.gr/en/products/detail/pui-audio-inc/AT-1224-TWT-12V-2-R/5011403 (https://www.digikey.gr/en/products/detail/pui-audio-inc/AT-1224-TWT-12V-2-R/5011403)
Multiplexer TC74HC4051APF | 1 | https://www.digikey.gr/en/products/detail/toshiba-s emiconductor-and-storag e/TC74HC4051APF/870 508 (https://www.digikey.gr/en/products/detail/toshiba-semiconductor-and-storage/TC74HC4051APF/870508)
Neodymium block magnet 10x5x1 thick N38 | 6 | https://euromagnesy.com/en/ndfeb-neodymium-bl ock-magnets-small-5-m m-10-mm/919-neodymiu m-block-magnet-10x5x1-thick-n38-590507250627 4.html?srsltid=AfmBOoq G9WObDhvC93B4OMTd cfK_K4pLFdm5ndKFSaw 0KmENt02GmwNh (https://euromagnesy.com/en/ndfeb-neodymium-block-magnets-small-5-mm-10-mm/919-neodymium-block-magnet-10x5x1-thick-n38-5905072506274.html)

Table 3. Electronic and Non-Printable Parts for Robot Assembly

3.2. The PCB boards
In this section, the user must have basic soldering skills to assemble the PCB for the robot. The PCB already has printed markings on its surface indicating where the electronic components should be soldered.

3.2.1 Main PCB
The PCB designs can be downloaded from Github: https://github.com/chronis10/fossbot-hardware/blob/fossbot-v2/electronics_instructions/Schematic_FOSSBot.pdf (https://github.com/chronis10/fossbot-hardware/blob/fossbot-v2/electronics_instructions/Schematic_FOSSBot.pdf)

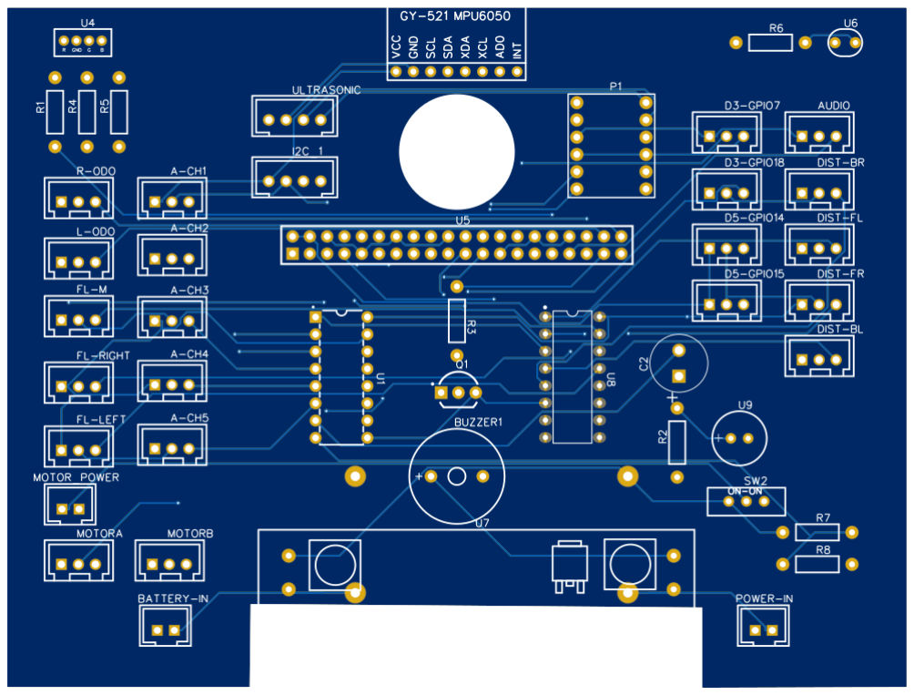
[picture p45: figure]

Figure 8. Front Side of PCB

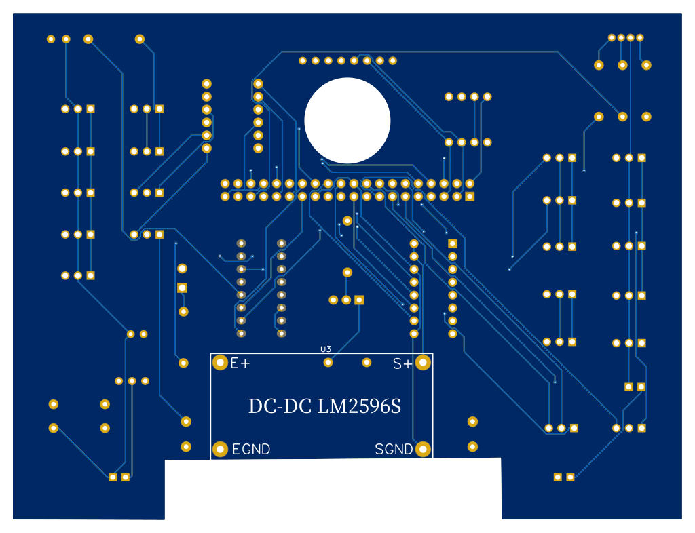
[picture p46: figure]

Figure 9. Back Side of PCB

Prepare the parts as shown in the following list, preheat your soldering tool, and start placing and soldering all the components.

IMU - MPU6050 (Accelerometer and Gyroscope) | 1 | U2

JST 4-pin male | 2 | I2C_1, ULTRASONIC
JST 3-pin male | 21 | A-CH1, A-CH2, A-CH3, A-CH4, A-CH5, AUDIO, D3-GPIO7, D3-GPIO18, D5-GPIO14, D5-GPIO15, DIST-BL, DIST-BR, DIST-FL, DIST-FR, FL-LEFT, FL-M, FL-RIGHT, L-ODO, MOTORA, MOTORB, R-ODO
JST 2-pin male | 3 | BATTERY-IN, MOTOR_POWER, POWER-IN
On/Off Switch PCB 3pin SPDT Switch | 1 | SW2
10K Resistor | 1 | R6

3K Resistor | 1 | R7
2.2K Resistor | 1 | R2
1K Resistor | 2 | R3, R8
270Ω Resistor | 3 | R1, R2, R5
4 Channels Bidirectional logic bit converter | 1 | P1
MCP3008 - 10bit 8 channel ADC SPI | 1 | U1

Photoresistor (LDR) | 1 | LDR - U6
DC-DC Step-Down 5.2V 5A | 1 | U7
DC-DC Converter Step-Down 5-35V 2A | 1 | U3
Multiplexer TC74HC4051APF | 1 | U8
Microphone capsule | 1 | U9
RGB LED Common Cathode | 1 | U4

Buzzer 12V | 1 | BUZZER1

Table 4. Electronic Components for PCB Assembly The PCB has printing on both the top and bottom, indicating where each component should be placed. Using the previous table as a reference, start placing and soldering all the components. Some components, such as capacitors, must be placed with the correct orientation. The correct orientation can be determined by checking the length of the component’s legs—the longer pin is positive, while the shorter pin is negative.

JST Connectors
Place all the JST connectors in their corresponding places.

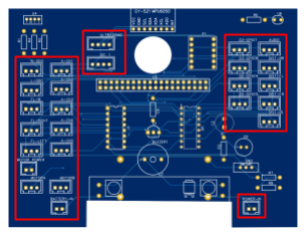
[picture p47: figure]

Figure 10. Placement of JST Connectors on PCB

RGB LED and LED resistors

Figure 11. Placement of RGB LED and LED resistors on PCB

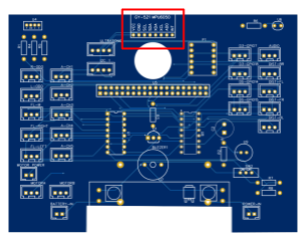
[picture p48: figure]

Accelerometer and Gyroscope

Figure 12. Placement of Accelerometer and Gyroscope on PCB

Bidirectional logic bit converter

Figure 13. Placement of Bidirectional logic bit converter on PCB

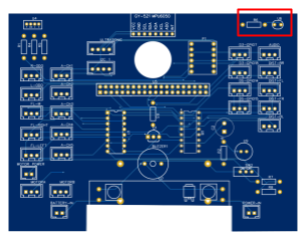
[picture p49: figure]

Photoresistor

Figure 14. Placement of Photoresistor on PCB

MCP3008 Analogue sensors reader

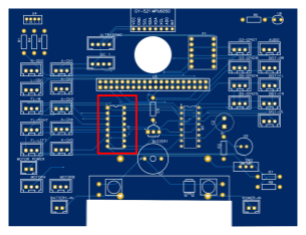
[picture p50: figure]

Figure 15. Placement of MCP3008 chip on PCB

Multiplexer

Figure 16. Placement of Multiplexer on PCB

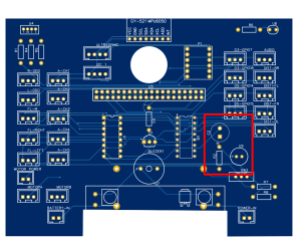
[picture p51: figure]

Noise sensor

Figure 17. Placement of Noise Sensor on PCB

On/Off Switch

Figure 18. Placement of On/Off Switch on PCB

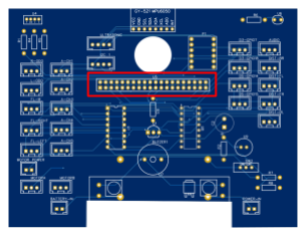
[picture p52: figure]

Raspberry Pi header

Figure 19. Placement of Raspberry Pi header on PCB

Buzzer

Figure 20. Placement of Buzzer on PCB

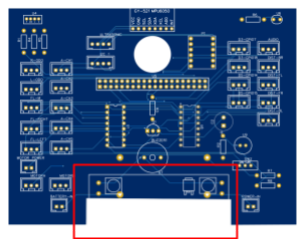
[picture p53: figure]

5V Step Down

Figure 21. Placement of 5V Step Down on PCB

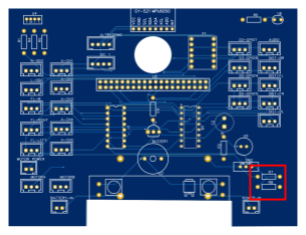
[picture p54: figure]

Power Sensor

Figure 22. Placement of Power Sensor on PCB

3.3V Step Down (Back Side of the PCB)

Figure 23. Placement of Step Down (Back Side of the PCB)

3.2.2 Battery pack PCB
The PCB designs can be downloaded from github: https://github.com/chronis10/fossbot-hardware/blob/fossbot-v2/electronics_instructions/Schematic_Battery.pdf (https://github.com/chronis10/fossbot-hardware/blob/fossbot-v2/electronics_instructions/Schematic_Battery.pdf)

Figure 24. Battery Pack for the PCB (front side)

Figure 25. Battery Pack for the PCB (back side)

JST 2-pin male | 1 | POWER
Battery holder 18650 | 3 | BT1, BT2, BT3
Li-ion Battery Charger Protection Module 3S 10A | 1 | BMS1

Table 5. Electronic Components for the Battery Pack of the PCB

Battery holders

Figure 26. Placement of Battery holders on battery pack

JST Connector

Figure 27. Placement of JST Connector on battery pack

BMS (Back Side of the PCB)

Figure 28. Placement of BMS Battery Protection Board on the back side of the battery pack

3.3 Wiring

An important step is the preparation of all sensors using the JST connector so that they can be easily attached to the main board later. The electronic components come with 3 or 4 male pin headers, and we need to convert these pins into JST connectors.
The following two images show examples of connecting an electronic component with a male pin header to a JST connector. One image illustrates a sensor with 3 pins, while the other shows a sensor with 4 pins. Similarly, you can connect any compatible sensor to the board, provided it is supported.

Figure 29. Connection of 3-pin and 4-pin sensors to JST connectors

The following images provide examples of these components and demonstrate how to connect them using the JST converter. You must repeat the same process for all components in the list below. The exact order of the connections may vary depending on how the component manufacturer assigns the outputs. Before starting the connection, please verify the corresponding pins and rearrange the connections if necessary.

Finally, some parts require soldering. These parts are indicated in the table below with a soldering requirement.

2x Dc motors (Soldering Required)

1x Dual Motor Driver Module

2x Photo Interrupter Sensor (Odometer)

Ultrasonic Distance Sensor

IR distance sensor analog

DC Power Jack (Soldering Required)

Loudspeaker (Soldering Required)

Audio Amplifier (Soldering Required)

Table 6. Electronic Components that require soldering

## 4. Assembly Instructions

After all the plastic parts have been printed, they need to be assembled. An important notice is to be take in mind that all the cables must be accessible from the top of the robot when complete the assembly in order to connect the JST connectors. During the limitation of the illustration is impossible to present the cabling so you must take care the proper cable management during the assembly using the internal grooves and slot in order to the end to drive all the cables on top of the PCB. The assembly instructions regarding the 3D-printed parts are the following :

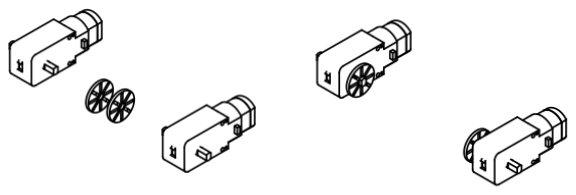
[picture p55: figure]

Figure 30. Odometer discs and motors

Figure 31. Place the motors on the bottom base

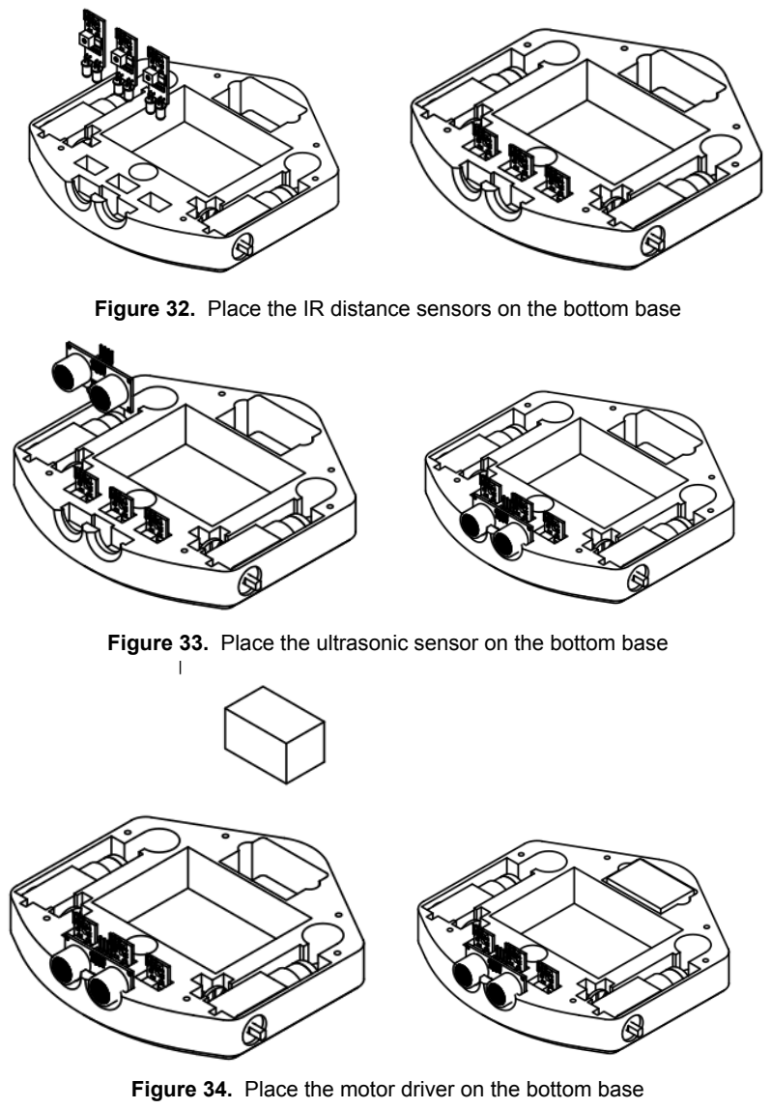
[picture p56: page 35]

Figure 32. Place the IR distance sensors on the bottom base

Figure 33. Place the ultrasonic sensor on the bottom base

Figure 34. Place the motor driver on the bottom base

Figure 35. Odometers sensors

Figure 36. Attach the wheels

Figure 37. Attach the spoilers

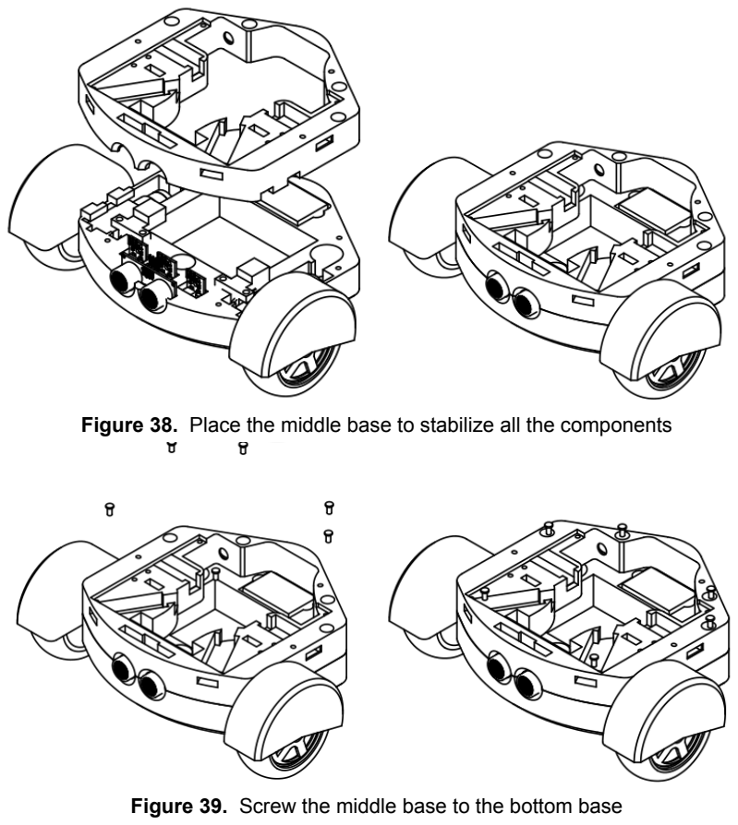
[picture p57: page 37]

Figure 38. Place the middle base to stabilize all the components

Figure 39. Screw the middle base to the bottom base

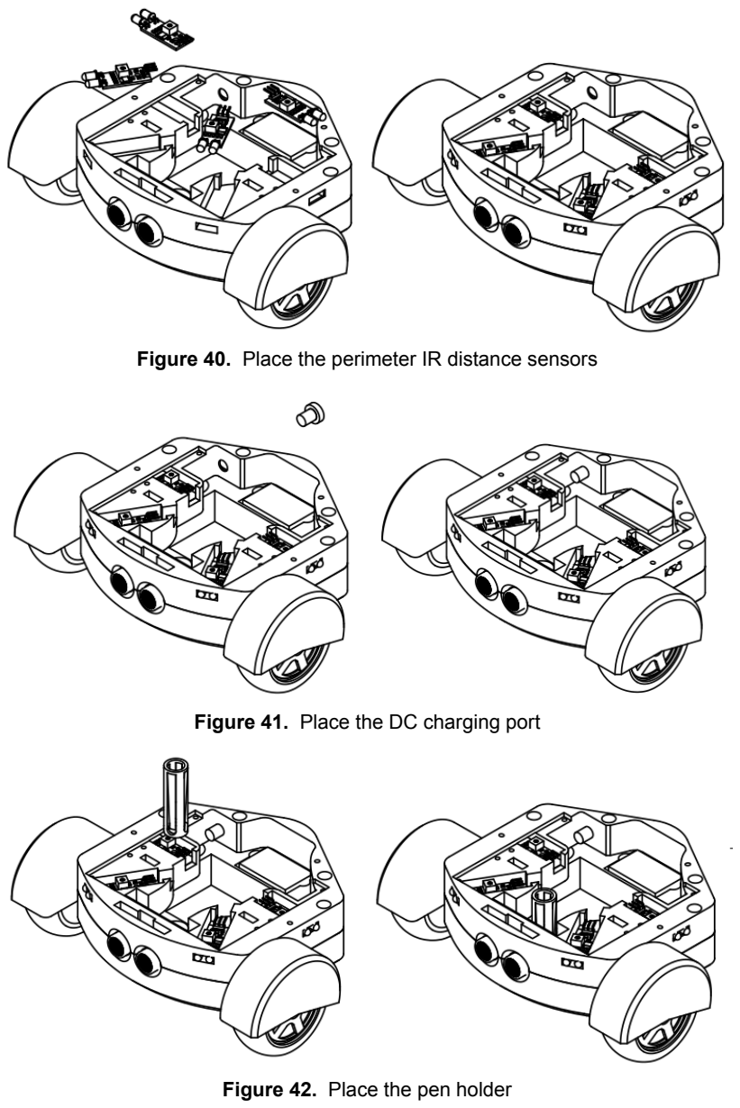
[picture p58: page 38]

Figure 40. Place the perimeter IR distance sensors

Figure 41. Place the DC charging port

Figure 42. Place the pen holder

Figure 43. Place the main PCB

Figure 44. Place the speaker on the top base

Figure 45. Place the top base on the middle base

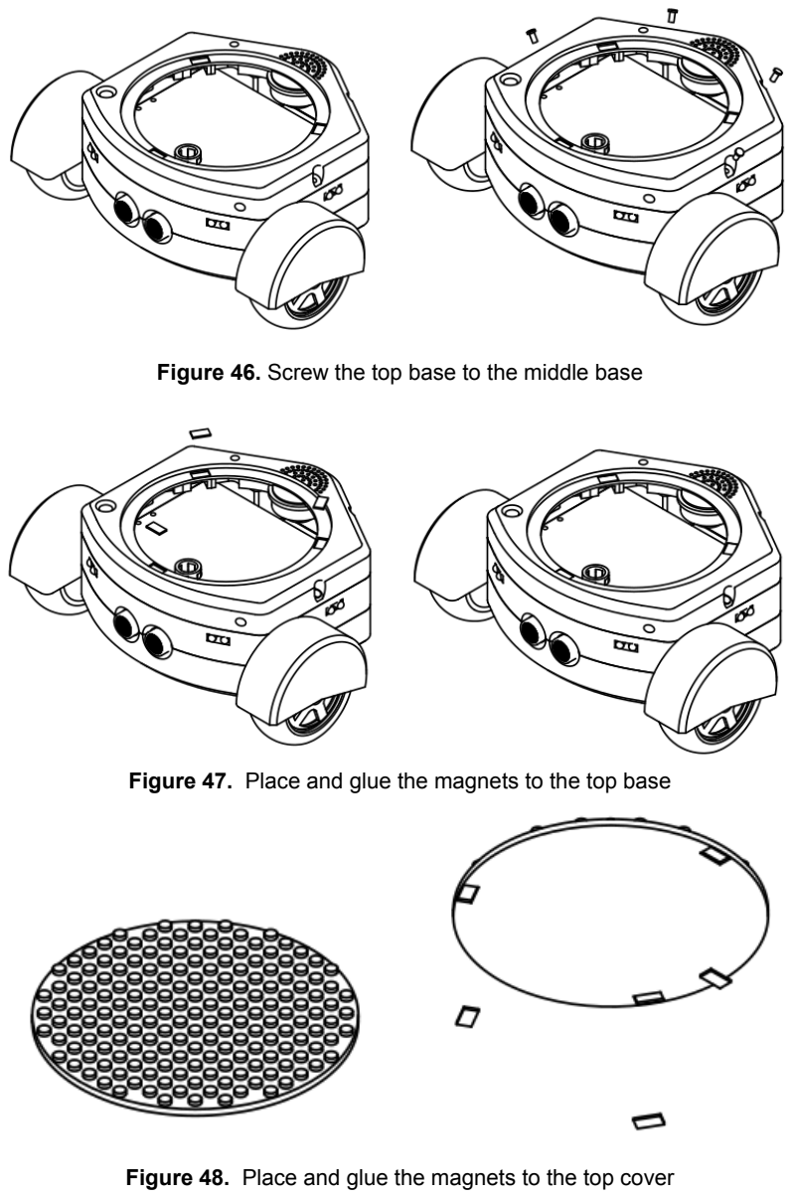
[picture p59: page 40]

Figure 46. Screw the top base to the middle base

Figure 47. Place and glue the magnets to the top base

Figure 48. Place and glue the magnets to the top cover

Figure 49. Place the top cover on the top base

Figure 50. Place the ball caster at the bottom of the robot

Figure 51. Screw the ball caster to the bottom

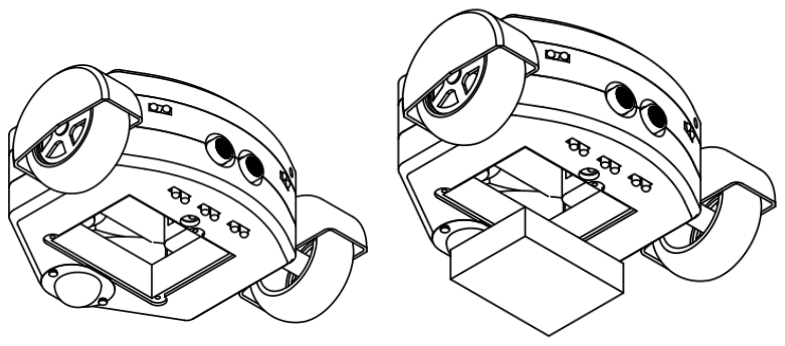
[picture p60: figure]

Figure 52. Place the battery pack

Figure 53. Place the battery cover

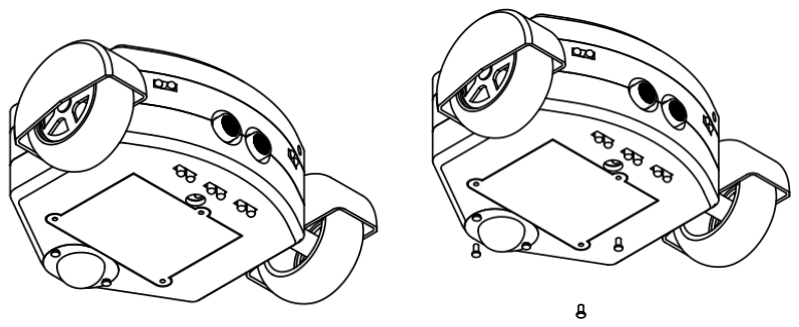
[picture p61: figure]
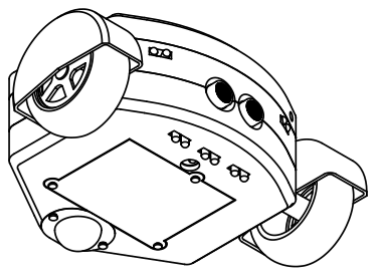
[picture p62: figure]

Figure 54. Screw the battery cover

Figure 55. The robot is ready

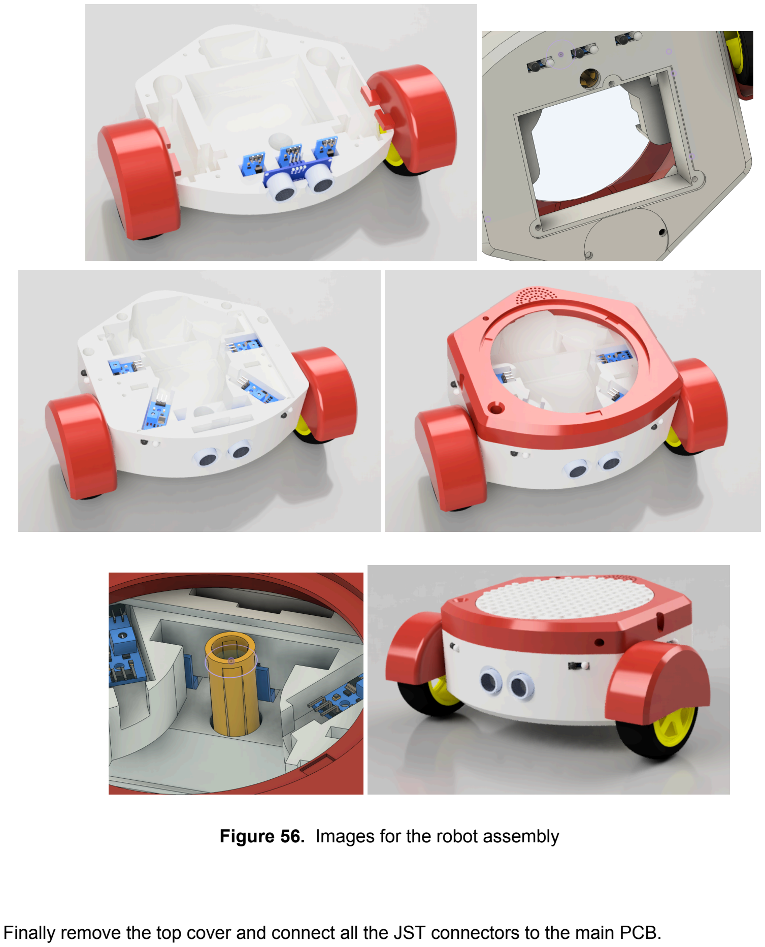
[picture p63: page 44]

Figure 56. Images for the robot assembly

Finally remove the top cover and connect all the JST connectors to the main PCB.

## 5. Setting up and running

Download the image file
- Download the newest version of the FOSSBot Image from the following link: ISO Images (http://83.212.81.212:8080/)
- Click on the first option (fossbot-app-v0.6-armv6-native.zip)
- Extract the downloaded zip. This will produce an iso .img file
- Download the Raspberry Pi imager from the following link: https://www.raspberrypi.com/software/

Installing the image
- Connect the microSD card from FOSSBot to your pc via a microSD adapter
- Open the Raspberry Pi imager program

Figure 57. Raspberry Pi imager

- Fill in the three fields:
🌕 Raspberry Pi Device: Raspberry Pi Zero

🌕 Operating System: Use custom(last option) / Choose the previously
| downloaded image
🌕 Storage: Choose the microSD card
- Press Next (you may need to format the card firstly)

Configuring the WIFI credentials
- After the successful installation, open in the boot partition of the microSD card the wifi_conig.txt file in your preferable editor
- Change the values ssid, psk and region according to your WiFi credentials

Figure 58. Wifi credentials in wifi_conig.txt file

- Save the file
- Safely detach the microSD card from your computer

Attach microSD card to FOSSBot
- Now you are ready to use the microSD card you configured to FOSSBot
- Attach the microSD card to Raspberry Pi Zero and power up the robot
- In a few seconds, you will see the LED sensor blinking red 🔴. This means that FOSSBot hasn’t detected your WiFi network yet
- In a few more seconds you will see the LED sensor blinking green 🟢. This means that FOSSBot has connected to your WiFi network but hasn’t established a connection to the internet yet
- Almost instantly the LED sensor will turn to blue and stay blue 🔵. This means that the connection to the internet is established
- Now you are ready to connect to the robot’s interface and start building projects! Just hit the link below to your browser: http://fossbot-000.local:8081
- This is what we must see:

Figure 59. FOSSBot Programming Interface Home Page

Happy coding!

## 6. Basic programming

Programming takes place in a visual programming environment called Blockly.

Blockly is a visual, block-based programming language developed by Google that allows users to create code by connecting puzzle-like blocks. Each block represents a code element, such as variables, loops, or functions, making it easy to learn and understand programming logic without needing to write traditional code. Designed for beginners, Blockly is often used in educational environments, like schools, to teach basic programming concepts. It supports various languages, including JavaScript and Python, enabling seamless transition to more advanced coding.

After activating FOSSBot you can enter either Kindergarten Mode or the Blockly customized workspace tailored specifically for robotics functions.

The simplest way to use and control FOSSBot is by selecting the Kindergarten Mode (under Instructions).

The view for younger ages is a very simple one. It contains cards with basic movements that the robot can execute, like moving back and forth. The logic is that the cards need to get dragged and dropped into the Blockly workspace. When the program is ready, by clicking the play button, the robot executes the movements on the cards one after the other. If the program needs to be stopped, the stop button needs to be clicked.

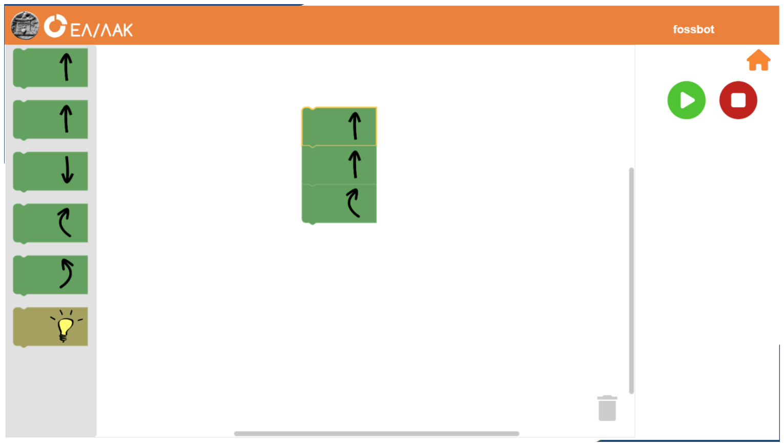
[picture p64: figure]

Figure 60. Kindergarten Mode

The second way to use and control FOSSBot is by using the Blockly page.

On the left side, the categories are shown. Each category contains a list of blocks. The blocks were split into categories to make it easier to look for them. Blocks can be dragged and dropped into the Blockly workspace to create programs that control FOSSBot.

On the right side of the screen, there is a black area where the results of the code are displayed in real-time.

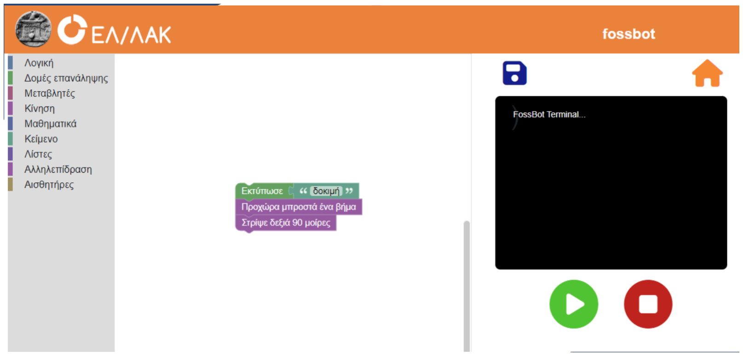
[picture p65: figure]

Figure 61. Blockly Page

Examples

Obstacle avoidance
In this example, the robot uses its ultrasonic distance sensor to avoid obstacles. When the ultrasonic distance sensor locates an object, then it checks the distance between the robot and the object found. In case the distance is less than 50 cm, the robot continues to move forward. Otherwise, it turns right. In Figure 5, the code for the obstacle avoidance example is presented. In Figure 6, the scene used for obstacle avoidance is where the robot moves between the cones without falling on them.

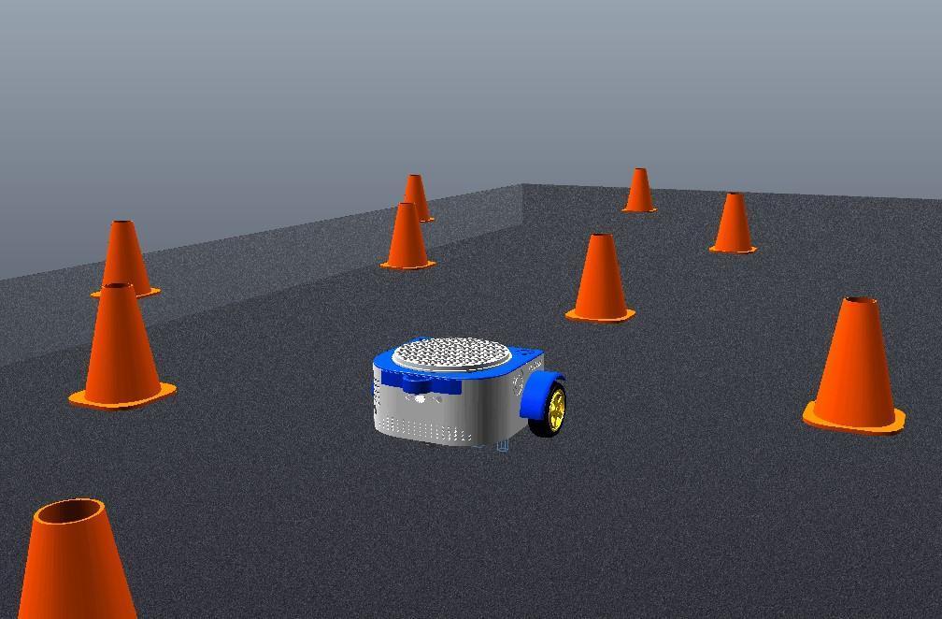
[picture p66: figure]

Figure 62. Code for obstacle avoidance Figure 63. Obstacle avoidance scene

Line following
In this example, the robot uses its IR obstacle sensor for line following and the ultrasonic distance sensor for obstacle avoidance. While there is no obstacle in front of the robot, the code checks if any of the IR sensors on the bottom of the robot are above the black line. This ensures that the robot moves in the right direction. Figure 7 shows an example code that can be used for line following. Figure 8 shows the scene where the robot moves by following a single continuous line.

Figure 64. Code for line following

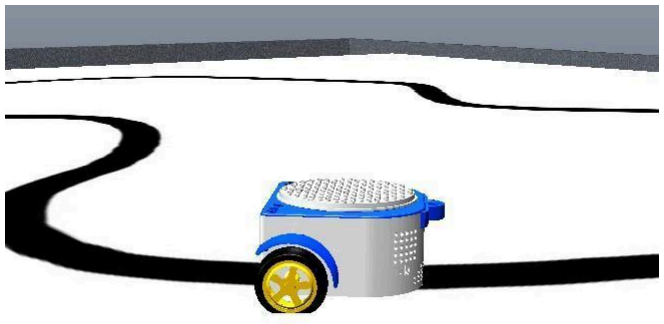
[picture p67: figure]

Figure 65. Line following scene

Light detection
In this example, the robot uses its light detection sensor for the detection of a bright or dark source. Based on the detection of a bright or dark source, the robot turns right or left. The RGB color light changes accordingly. In Figure 9, the code for detecting a bright source is presented. Figure 10 shows the scene used for light detection, where a bright source is included.

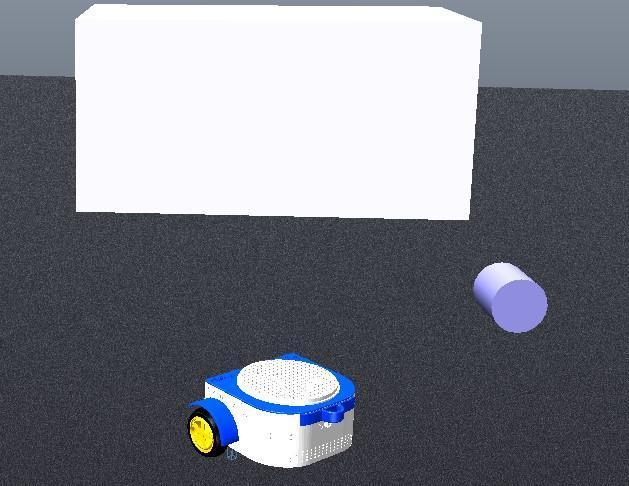
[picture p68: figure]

Figure 66. Light detection scene Figure 67. Light detection scene

## 7. Troubleshooting tips

1. Power off before soldering.

ASSEMBLY ISSUES
2. If plastic parts do not fit because of the edges, they can get sanded with fine-grit sandpaper.
3. Make sure the .stl files used for printing are correct.
4. In case plastic parts were falsely printed, reprint them.

BATTERY ISSUES
5. If you press the ON/ OFF button and the robot does not start, make sure the batteries are inserted correctly and the wiring is correct. Power should be able to run through the whole circuit.
6. If you press the ON/ OFF button and the robot does not start, maybe the batteries are not charged. Please charge the robot.
7. Robot turns off randomly, batteries may be empty. Please charge the robot.

WIFI CONNECTION PROBLEMS
8. Check wiifi_config.txt, please check if credentials are correct.
9. Please check if there is a wifi connection.
10.If there is a wifi connection but no good signal, please place the robot closer to the WIFI router.

PROGRAMMING ISSUES
11. If you press play in the Blockly page and the robot does not execute some of the blocks, ensure that blocks are snapped together correctly.
12.If you continue having issues with the execution, you can use debug prints.
13. If you press play in the Blockly page and the robot does not execute the blocks, check the connection.
14.No blue light? Recheck the commands for set up in Section 5.
15. Before running a “Follow the line” example, make sure the light detection sensors on the bottom of the robot are correctly configured. Configure the sensors in the Setting’s page.

## 8. Glossary

Term | Description
3D printed part | The part was printed using a 3D printer using the material provided to the printer.
Blockly | Visual, | block-based | programming
language developed by Google that allows users to create code by connecting puzzle-like blocks.
Blockly workspace | The area that contains all the blocks
connected to each other.
Github | GitHub is a developer platform that allows
developers to create, store, manage, and share their code.
IR distance sensor analog | Device that uses infrared light to measure distance, and its output is a continuously varying voltage that corresponds to the distance.
JST Connectors | It is a vernacular term for a range of different type of wire to board connectors.
Li-ion Battery Charger Protection Module | It is an electronic circuit to ensure safe operations within the lithium-ion batteries.
Battery Li-ion | Type of rechargeable battery.
microSD | A type of very small memory card typically used in mobile phones and other portable devices.
microSD adapter | Together with the microSD card, comes the adapter so that the micro sd card can be used in regular sd card slot on a computer, laptop, camera, or whatever might have a regular sd card slot.
Odometer | Instrument used for measuring the distance traveled by a vehicle.
PCB Board | It is an electronic assembly that uses

| copper conductors to create electrical connections between components. PCBs also provide mechanical support for electronic components so that a device can be mounted in an enclosure.
Photoresistor | Type of resistor that changes its resistance based on the intensity of light shining on it.
Photo Interrupter Sensor | It is a sensor with a light-emitting component and light-receiving component packaged face to face. It applies the principle that light is interrupted when an object passes through the sensor.
Raspberry PI | Series of low-cost, small single board computers created by teh Raspberry Pi Foundation in collaboration with Broadcom.
Raspberry Pi Imager | A tool for writing an OS (Operating System) to an SD card
Resistor | Device having resistance to the passage of an electric current.
RGB LED | It is a LED module that can produce almost any color using these three primary additive colors: Red, Green and Blue.
stl file | It is a common file format for 3D printing and computer-aided design (CAD). It stores the surface geometry of a 3D object using a series of triangular facets, effectively creating a "mesh" of the object's outer shape.
WAVESHARE IR proximity sensor with analog | The sensor uses infrared transmitter and receiver tubes for obstacle detection.

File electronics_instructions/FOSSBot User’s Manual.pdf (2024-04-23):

# FOSSBot User’s Manual

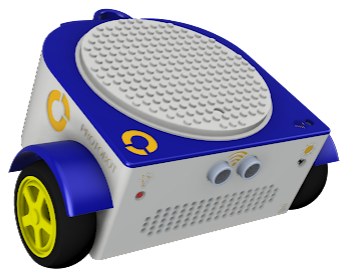
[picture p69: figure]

Power ON/OFF and Charging Port (12V)

Section A: First Use

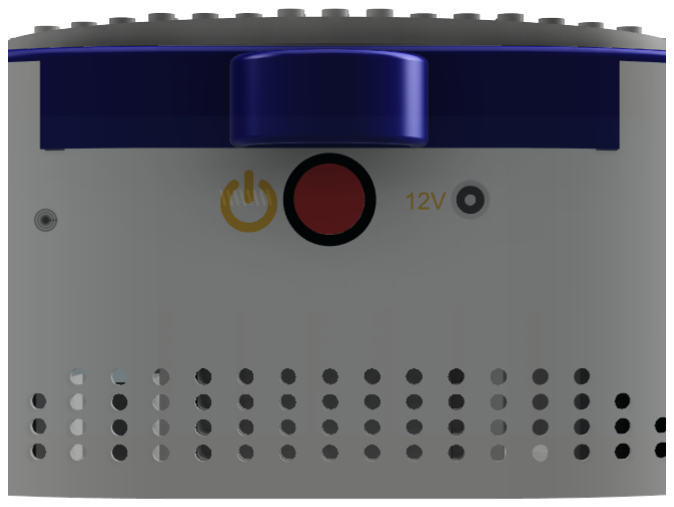
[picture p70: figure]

1. Power ON the robot. All the LEDs will light up.
2. Wait a few seconds for the system to initialize.
3. Grab your phone and search for a Wi-Fi network named fossbot-xxx. (The network might be delayed in appearing, so wait a few more seconds and search again if necessary.)

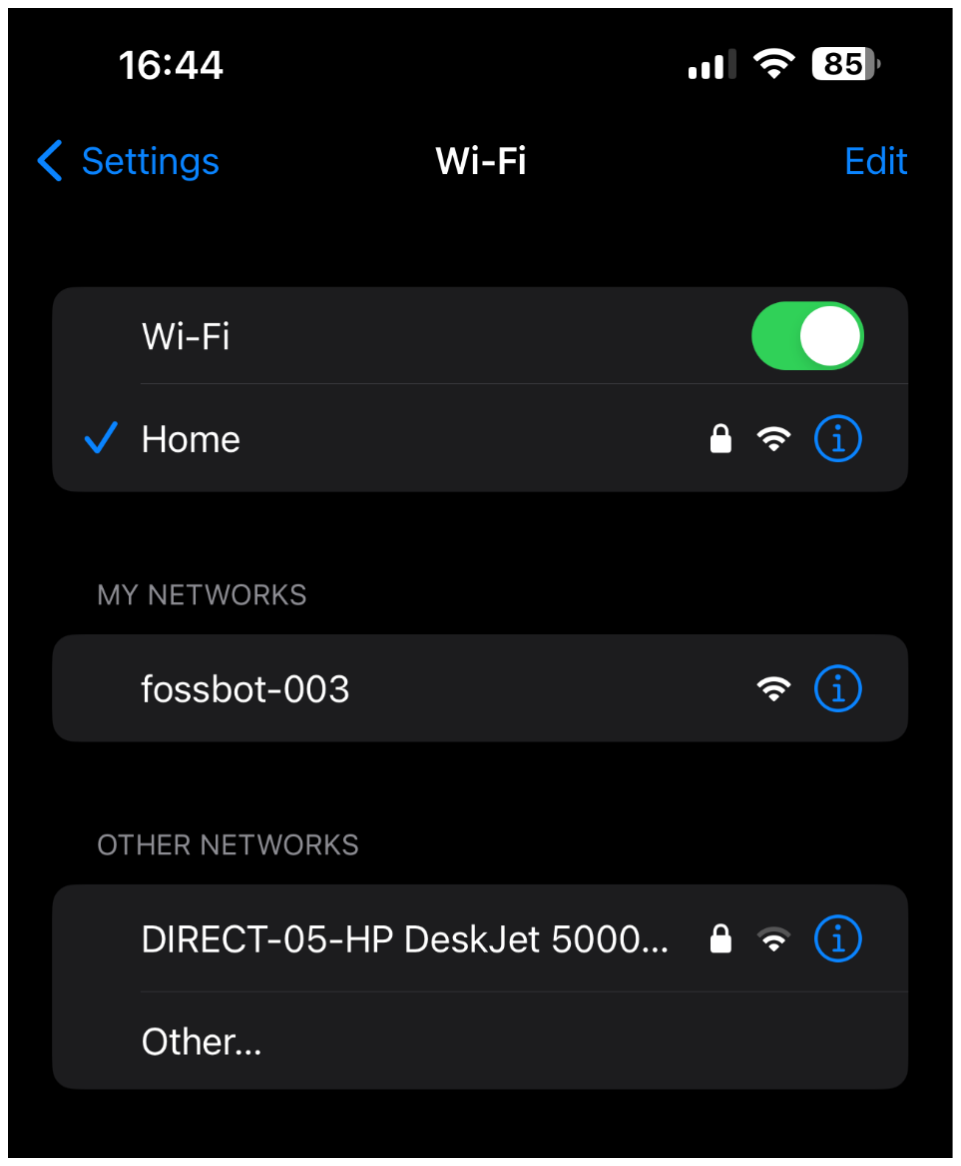
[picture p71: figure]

4. Connect to the fossbot network.

5. A pop-up will appear, allowing you to select your home network.

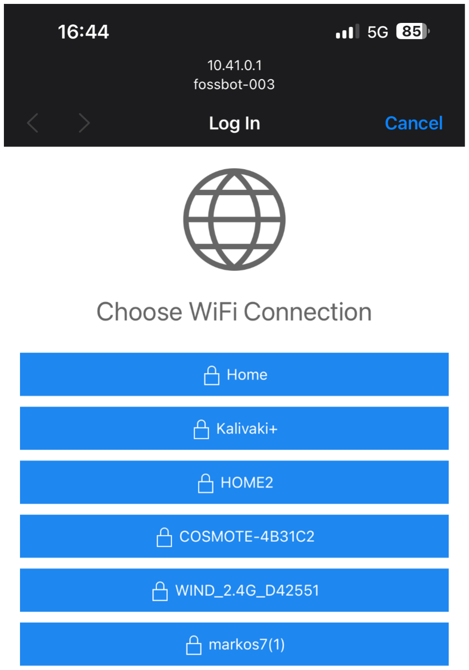
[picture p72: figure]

6. Enter your Wi-Fi password and press 'Connect'.

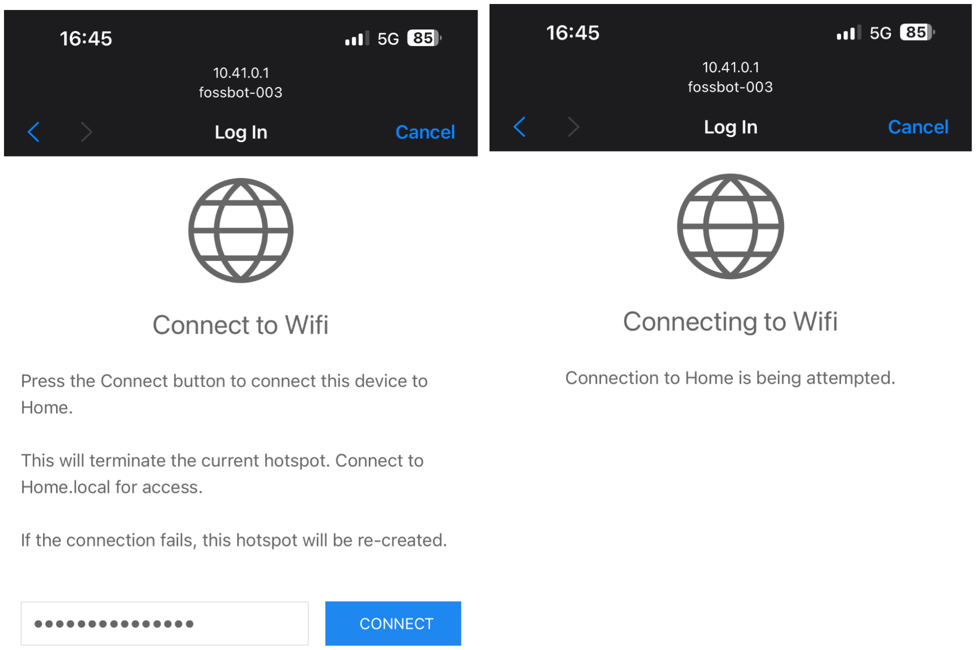
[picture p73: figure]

7. From now on, the robot will automatically connect to your home network.

Notes:
- If you move the robot to a new location, follow these steps again. The robot automatically stores all previously connected networks.
- After a successful connection to your home network, the fossbot access point will disappear.

Section B: Subsequent Uses

1. Power ON the robot.
2. On a PC or laptop connected to the same network as the robot, open Chrome or Firefox and go to the URL: http://fossbot-000.local:8081
3. You should now see the robot interface.

FAQ

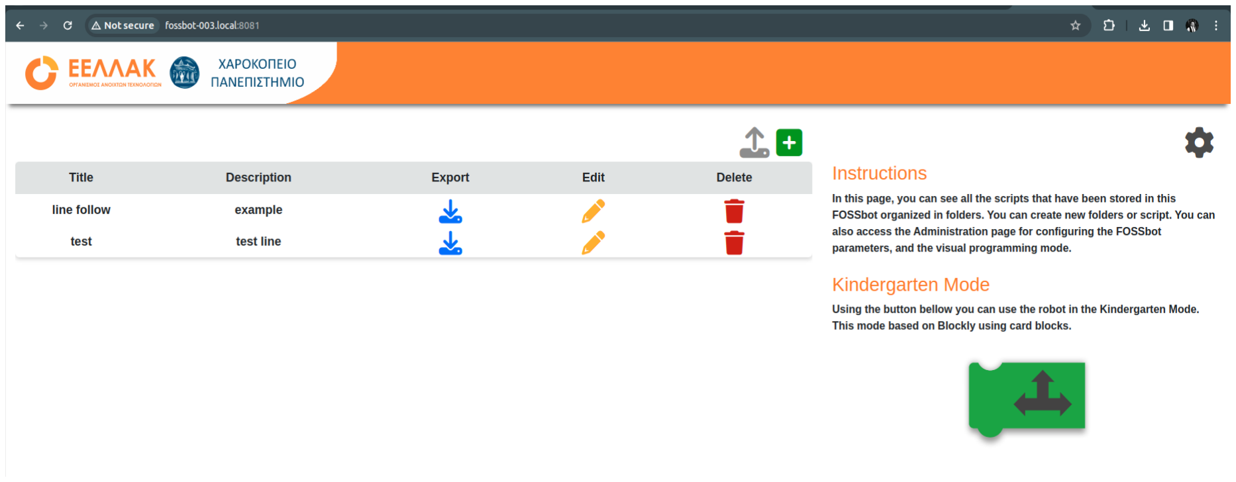
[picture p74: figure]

Q: I can't find the robot network on my phone. What should I do?

A1: If it's the first time the robot is activated in a new location with an unknown network, turn the robot OFF and ON again, and search for the network. Additionally, wait a few seconds for the system to automatically start in access point mode.
A2: If you have completed the first-run steps, the access point mode is automatically disabled. Follow the steps from Section B.

Q: The pop-up screen from the access point disappeared or I accidentally closed it.

A: Open Chrome on your mobile phone and go to the URL: http://10.41.0.1/

Q: I completed the steps from Section A but can't access the URL http://fossbot-000.local:8081

A: In some cases, the router may not automatically recognize the local hostname fossbot-000.local. In these cases, open your router's admin page, search for the robot's IP, and use that IP instead of the hostname (e.g., http://192.168.1.xxx:8080).

Robot Configuration:
Most of the robot's predefined settings, including language, can be modified through the cog icon at the top right on the home screen of the robot.

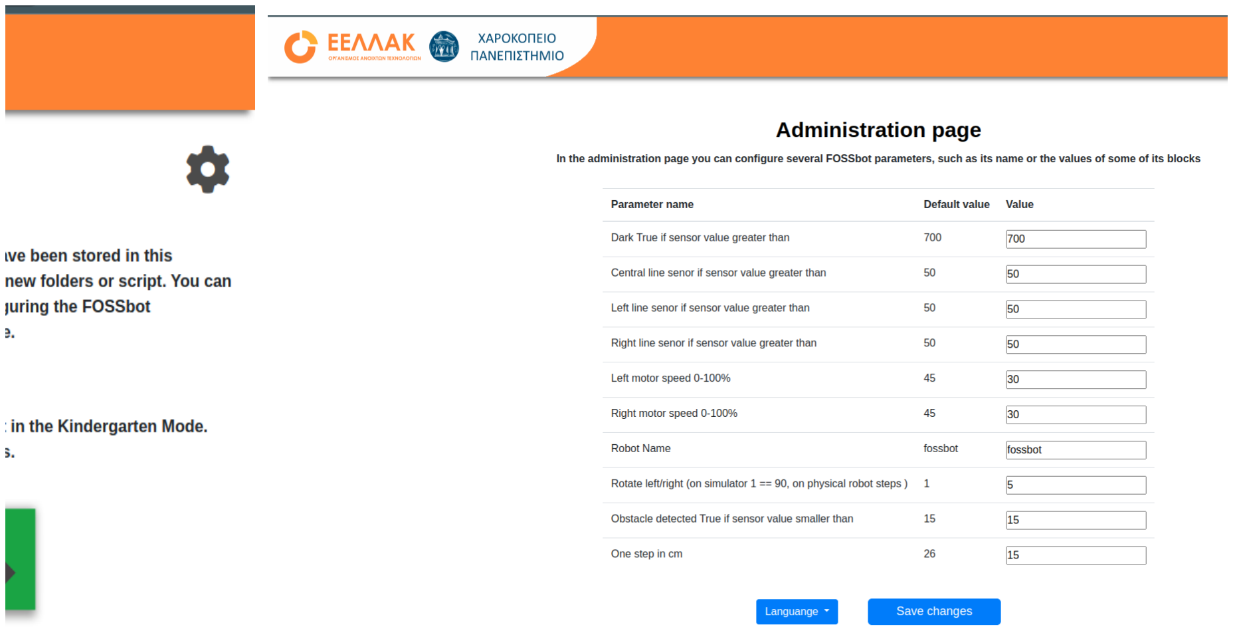
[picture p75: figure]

Advanced Users:

- The robot has SSH access preactivated. Access the robot via SSH at pi@fossbot-000.local with the password 'raspberry'.
- To edit/delete networks and change the hostname, use the preinstalled comitup tool with the command sudo comitup-cli.

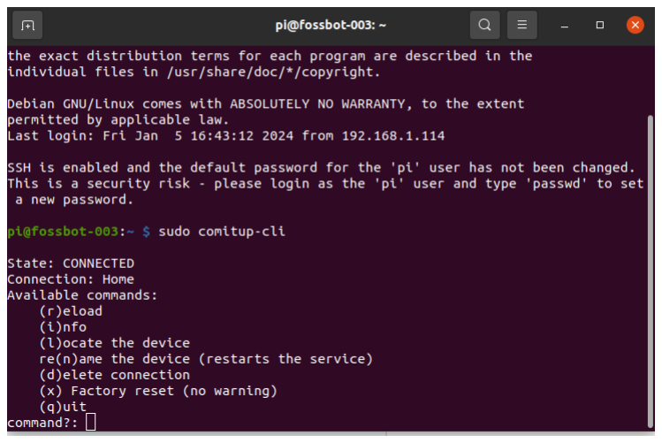
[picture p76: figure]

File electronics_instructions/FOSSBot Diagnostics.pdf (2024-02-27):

# FOSSBot Hardware Diagnostics Manual

At first you need to:
- power on the robot
- connect it to the Wi-Fi
- establish ssh connection with the robot using ssh pi@fossbot-000.local with the password ‘raspberry’.
All the above steps are explained here. (https://edu.ellak.gr/wp-content/uploads/sites/11/2024/01/FOSSBot-Users-Manual.pdf)
1. Once you've successfully established the SSH connection and accessed the FOSSBot, use the 'ls' command to inspect the contents.
2. Run the command ‘cd diagnostics’ to enter the diagnostics directory. Use again the ‘ls’ command to inspect the contents of the directory.
3. Execute the run_diagnostics.sh script by running ‘./run_diagnostics.sh’.
4. Now execute the diagnostics python script by running ‘python diagnostics.py’.

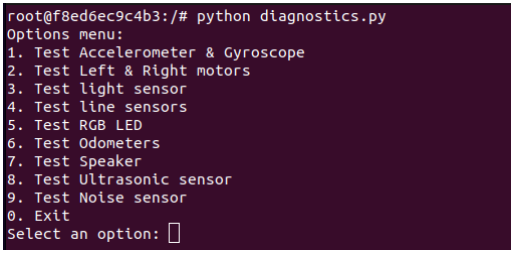
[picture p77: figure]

## From here you can execute diagnostic checks for all the sensors and

hardware components of the robot.

## Select option 1:

Press 1 and then ‘Enter’

You will see some metrics about the Accelerometer and Gyroscope sensors.

Check:
If you move the robot with your hands, left and right and the metrics change this means that sensors are working correct.

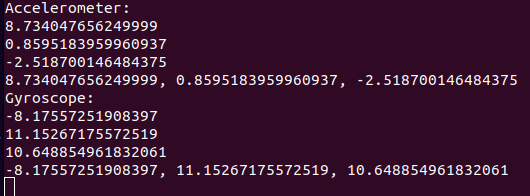
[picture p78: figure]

Exit check:
Press Ctrl and C to exit this option.

## Select option 2:

Press 2 and then ‘Enter’

In this option you can check that the motors are working correctly.

Check:

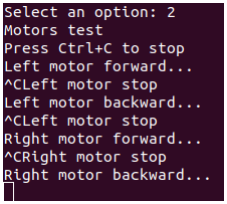
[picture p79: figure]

At first the left motor moves the robot forward. Press Ctrl and C to continue.
Now the left motor moves the robot backwards. Press Ctrl and C to continue.
Now the right motor moves the robot forward. Press Ctrl and C to continue.
Now the right motor moves the robot backwards.

Exit check:
Press Ctrl and C to exit this option.

## Select option 3:

Press 3 and then ‘Enter’

In this option you can check that the light sensor is working correctly.

Check:

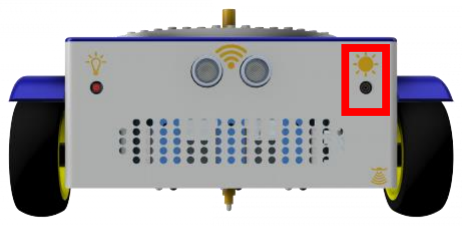
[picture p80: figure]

At first cover the light sensor. Now that the light sensor is in the dark the output should be a low integer number.

Then use a flashlight and point it to the light sensor. Now you should see the integer value increasing.

Exit check:
Press Ctrl and C to exit this option.

## Select option 4:

Press 4 and then ‘Enter’

In this option you can check that the IR sensors are working correctly.

Check:

At first the indications refer to the middle IR sensor.

If you cover the sensor with your hand, you must see a low integer number like on the left picture.

If you uncover the sensor and allow it sufficient you should observe the number increasing like on the right picture.

Press Ctrl and C to continue.

Now the indications refer to the right IR sensor.

If you cover the sensor with your hand, you must see a low integer number like on the left picture.

If you uncover the sensor and allow it sufficient you should observe the number increasing like on the right picture.

Press Ctrl and C to continue.

Now the indications refer to the left IR sensor.

If you cover the sensor with your hand, you must see a low integer number like on the left picture.

If you uncover the sensor and allow it sufficient you should observe the number increasing like on the right picture.

Exit check:
Press Ctrl and C to exit this option.

## Select option 5:

Press 5 and then ‘Enter’

In this option you can check that the LED sensor is working correctly.

Check:

Initially, the LED sensor emits a visible red light.

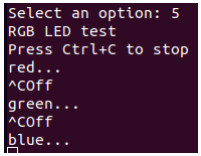
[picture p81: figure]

Press Ctrl and C to continue.

Now the LED sensor emits a visible green light.

Press Ctrl and C to continue.

Now the LED sensor emits a visible blue light.

Exit check:
Press Ctrl and C to exit this option.

## Select option 6:

Press 6 and then ‘Enter’

In this option you can check that the odometers of the robot are working correctly.

Check:

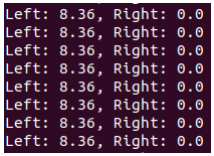
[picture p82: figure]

In this image, you can observe the odometers. Manipulating the left wheel of the robot should result in an increase in the left number, while adjusting the right wheel should cause the right number to increment.

Exit check:
Press Ctrl and C to exit this option.

## Select option 7:

Press 7 and then ‘Enter’

In this option you can check that the speaker of the robot is working correctly.

Check:

You should hear the r2d2.mp3 playing and see this:

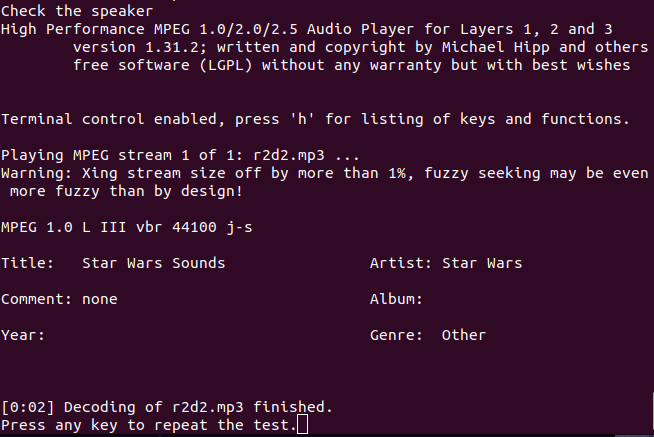
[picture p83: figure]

Exit check:
Press Ctrl and C to exit this option.

## Select option 8:

Press 8 and then ‘Enter’

In this option you can check that the ultrasonic sensor is working correctly.

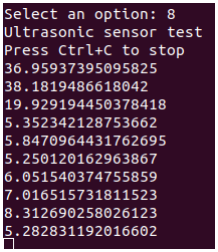
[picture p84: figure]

Check:

As you move your hand in front of the ultrasonic sensor, you will notice that the output value decreases as you approach it and increases as you move away.

Exit check:
Press Ctrl and C to exit this option.

## Select option 9:

Press 9 and then ‘Enter’

In this option you can check that the noise sensor is working correctly.

Check:

The output value should be False and when you produce a noise, like clapping your hands, the value should instantly change to True.

Exit check:
Press Ctrl and C to exit this option.

## Disconnect from the robot


Press 9 and then ‘Enter’ to exit the python script.

Type exit and then ‘Enter’ to exit from the diagnostics
container.

Type exit and then ‘Enter’ to logout from the ssh connection.

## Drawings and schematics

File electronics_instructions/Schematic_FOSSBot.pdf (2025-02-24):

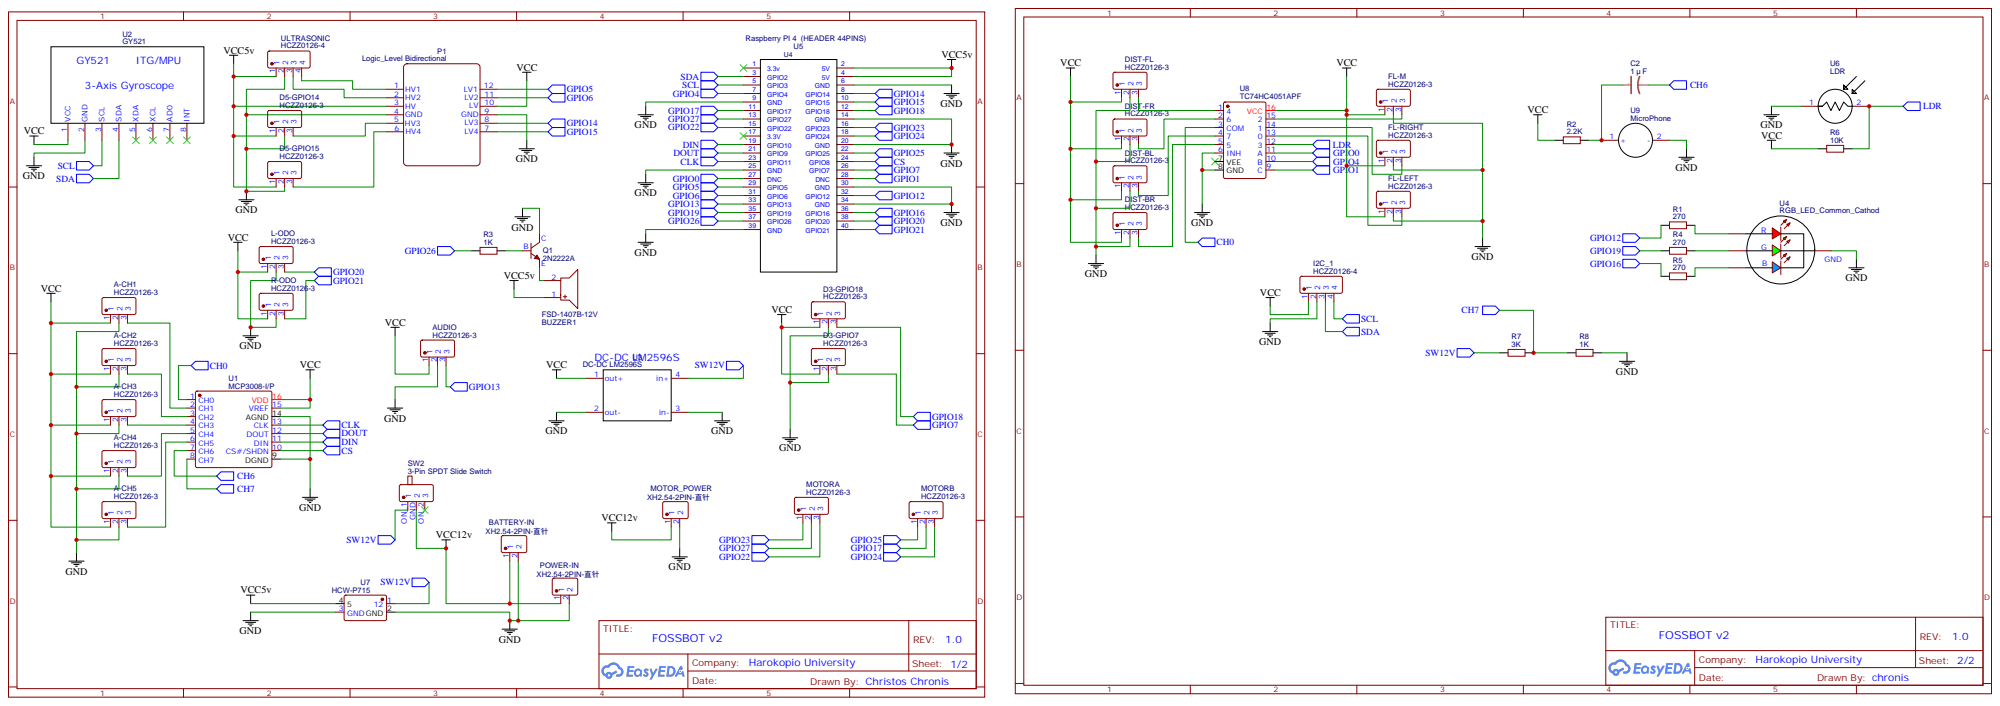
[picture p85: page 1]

3-Pin SPDT Slide Switch

Drawn By: Christos Chronis

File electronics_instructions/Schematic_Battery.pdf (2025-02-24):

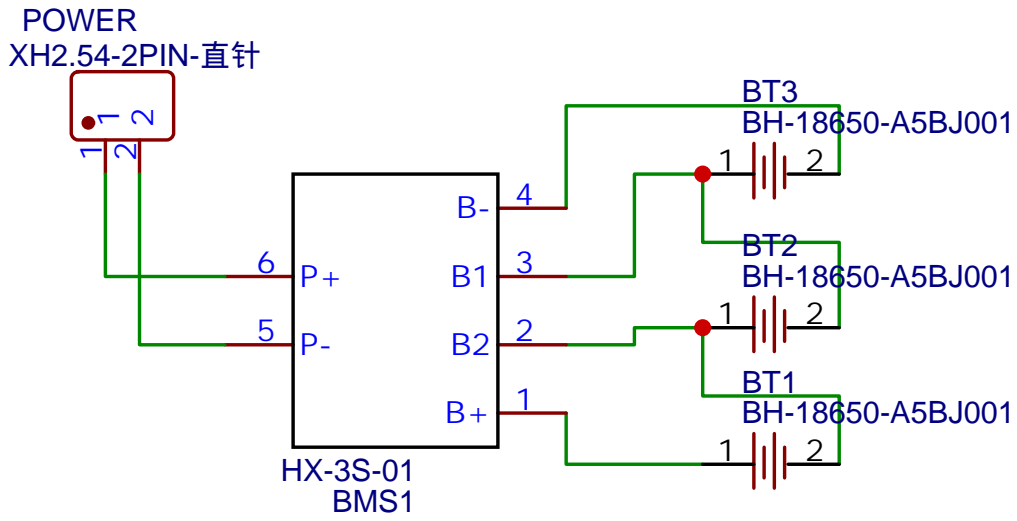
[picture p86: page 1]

Drawn By: Christos Chronis

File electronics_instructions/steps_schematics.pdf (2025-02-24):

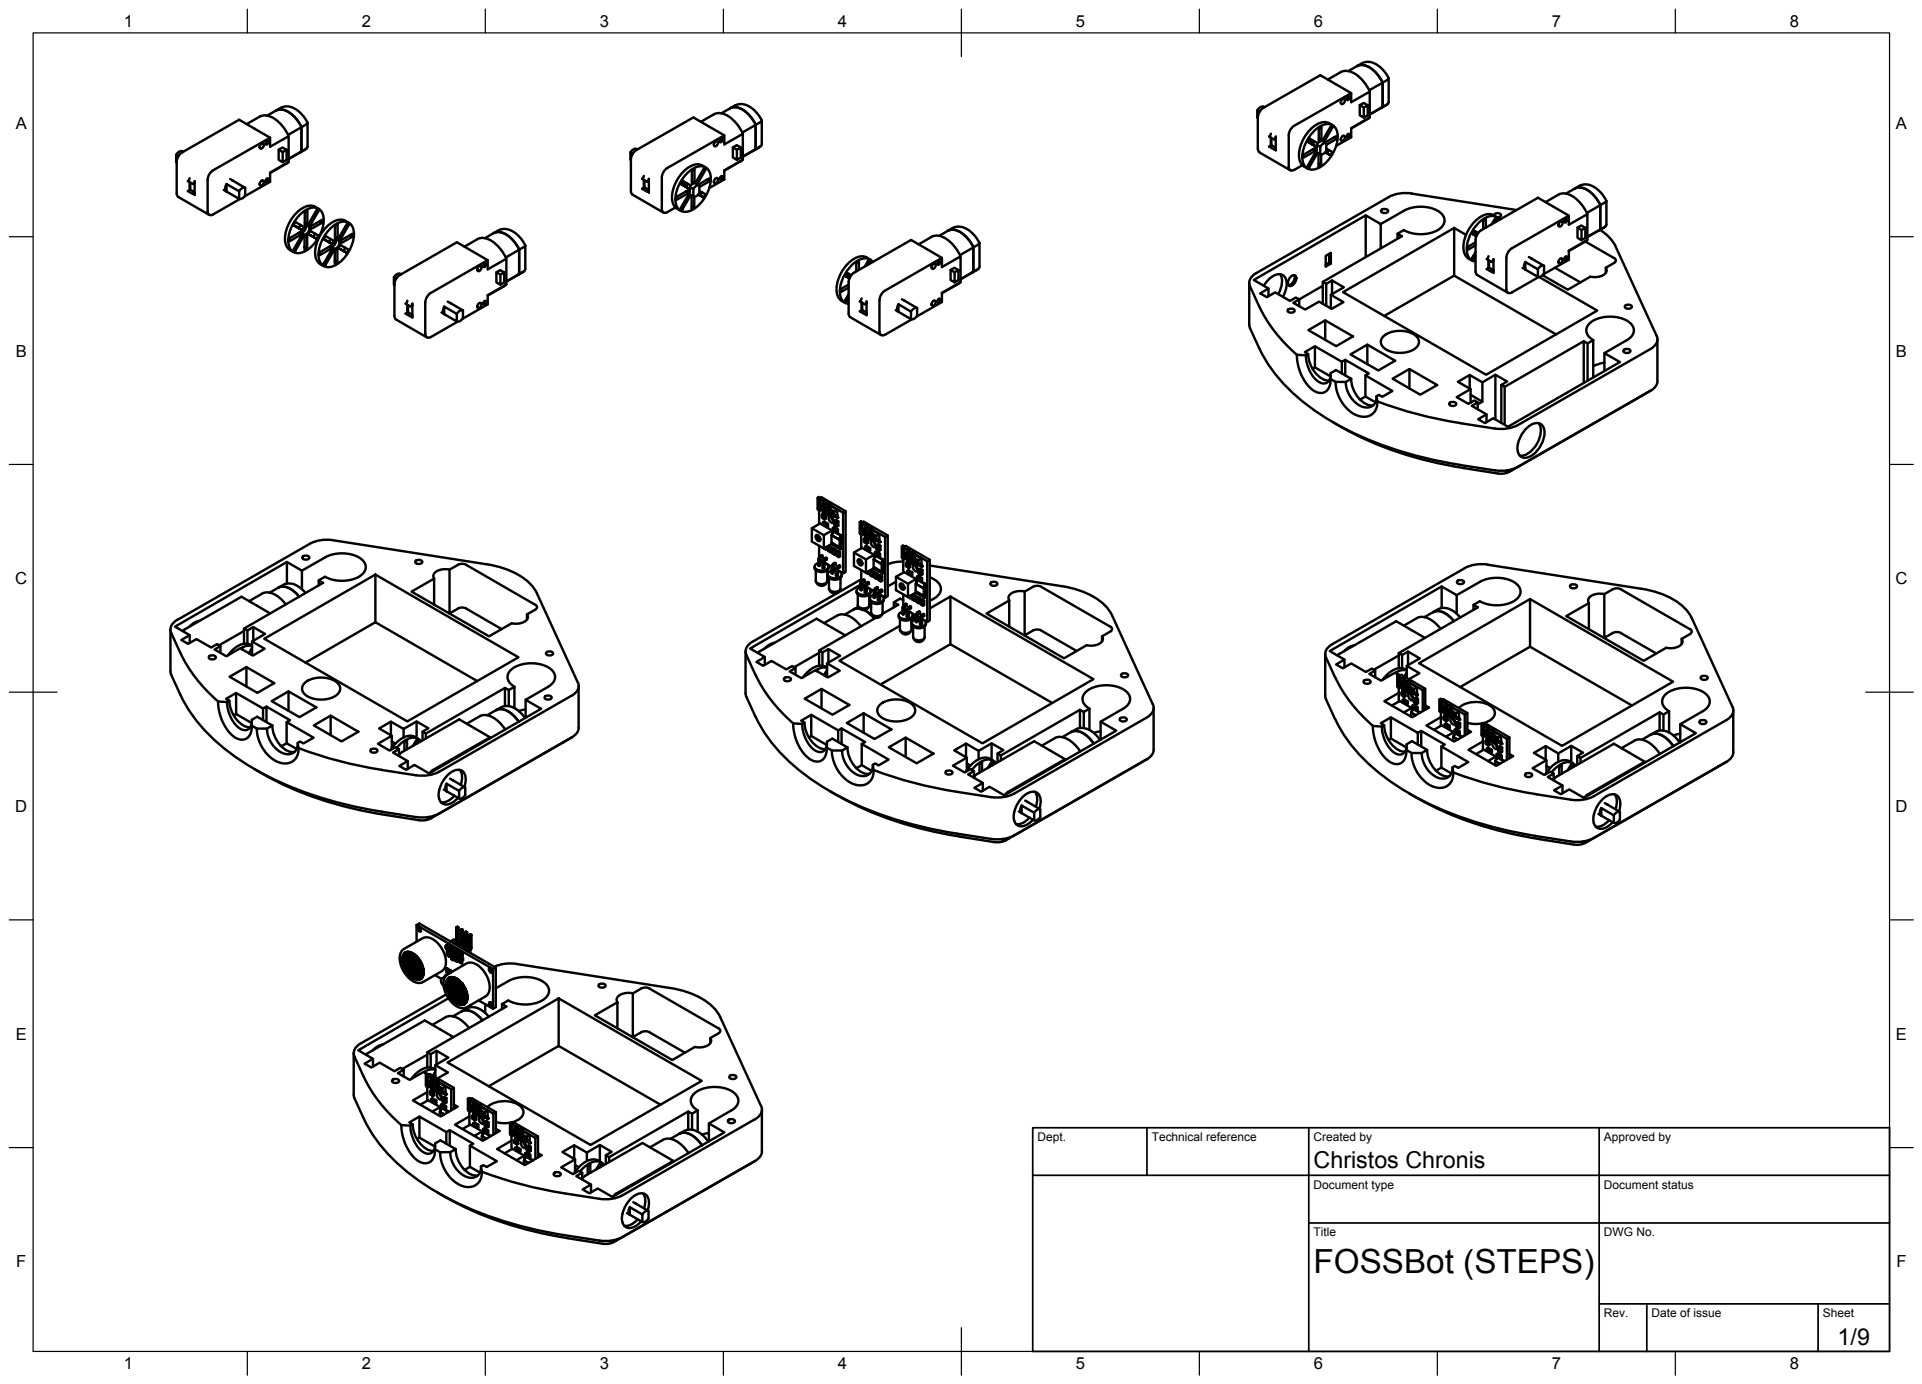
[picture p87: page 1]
Title; DWG No.; Rev.; Date of issue; Sheet; FOSSBot (STEPS)

Dept. | Technical reference | Created by Christos Chronis | Approved by

Document type | Document status

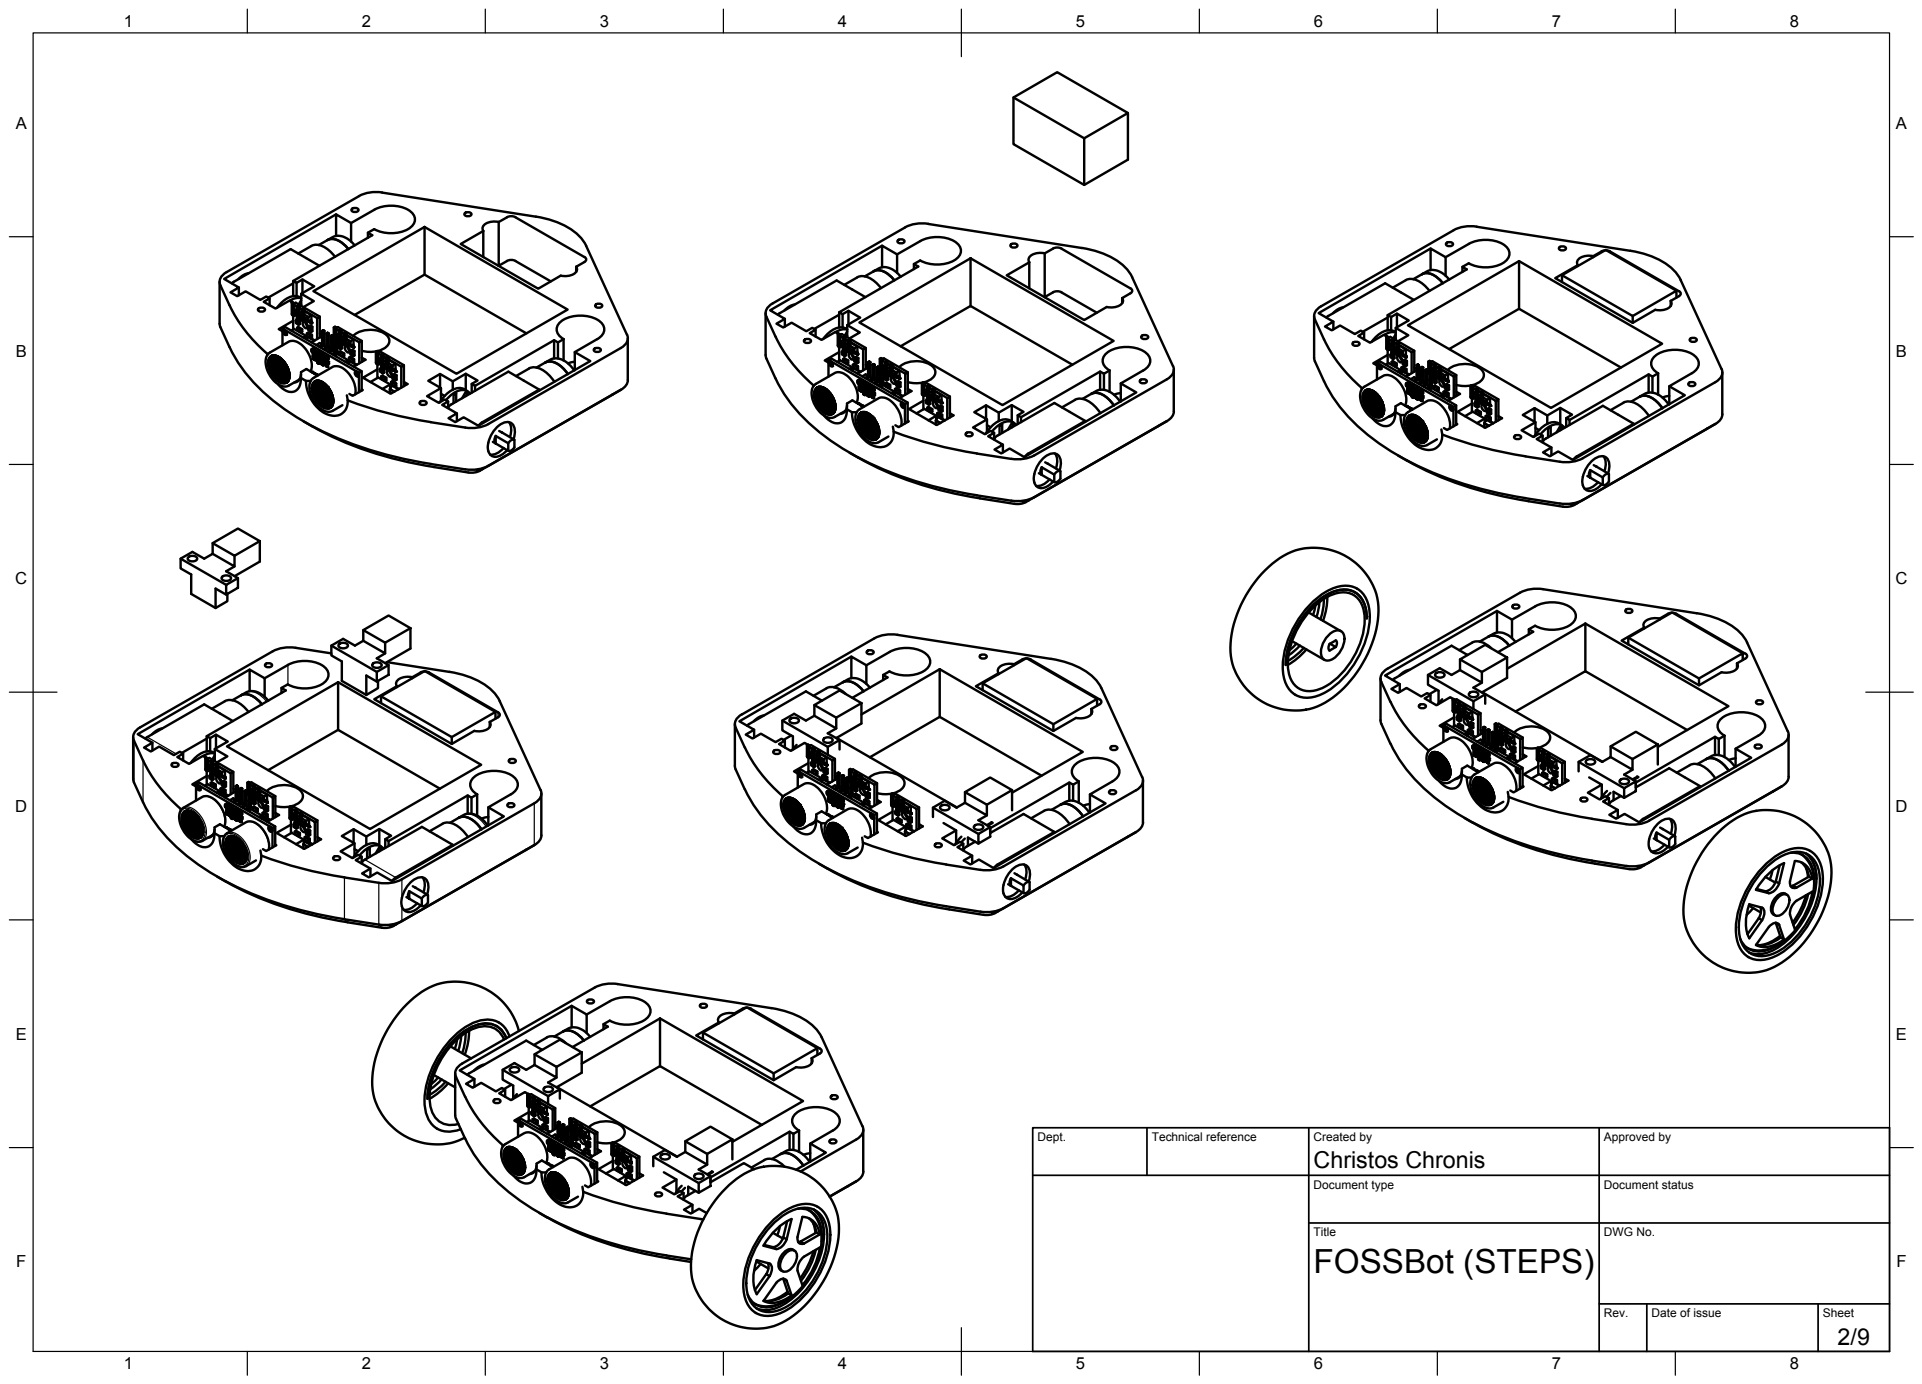
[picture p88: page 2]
Dept.; Technical reference; Created by; Approved by; Document type; Document status; Title; DWG No.; FOSSBot (STEPS); Christos Chronis

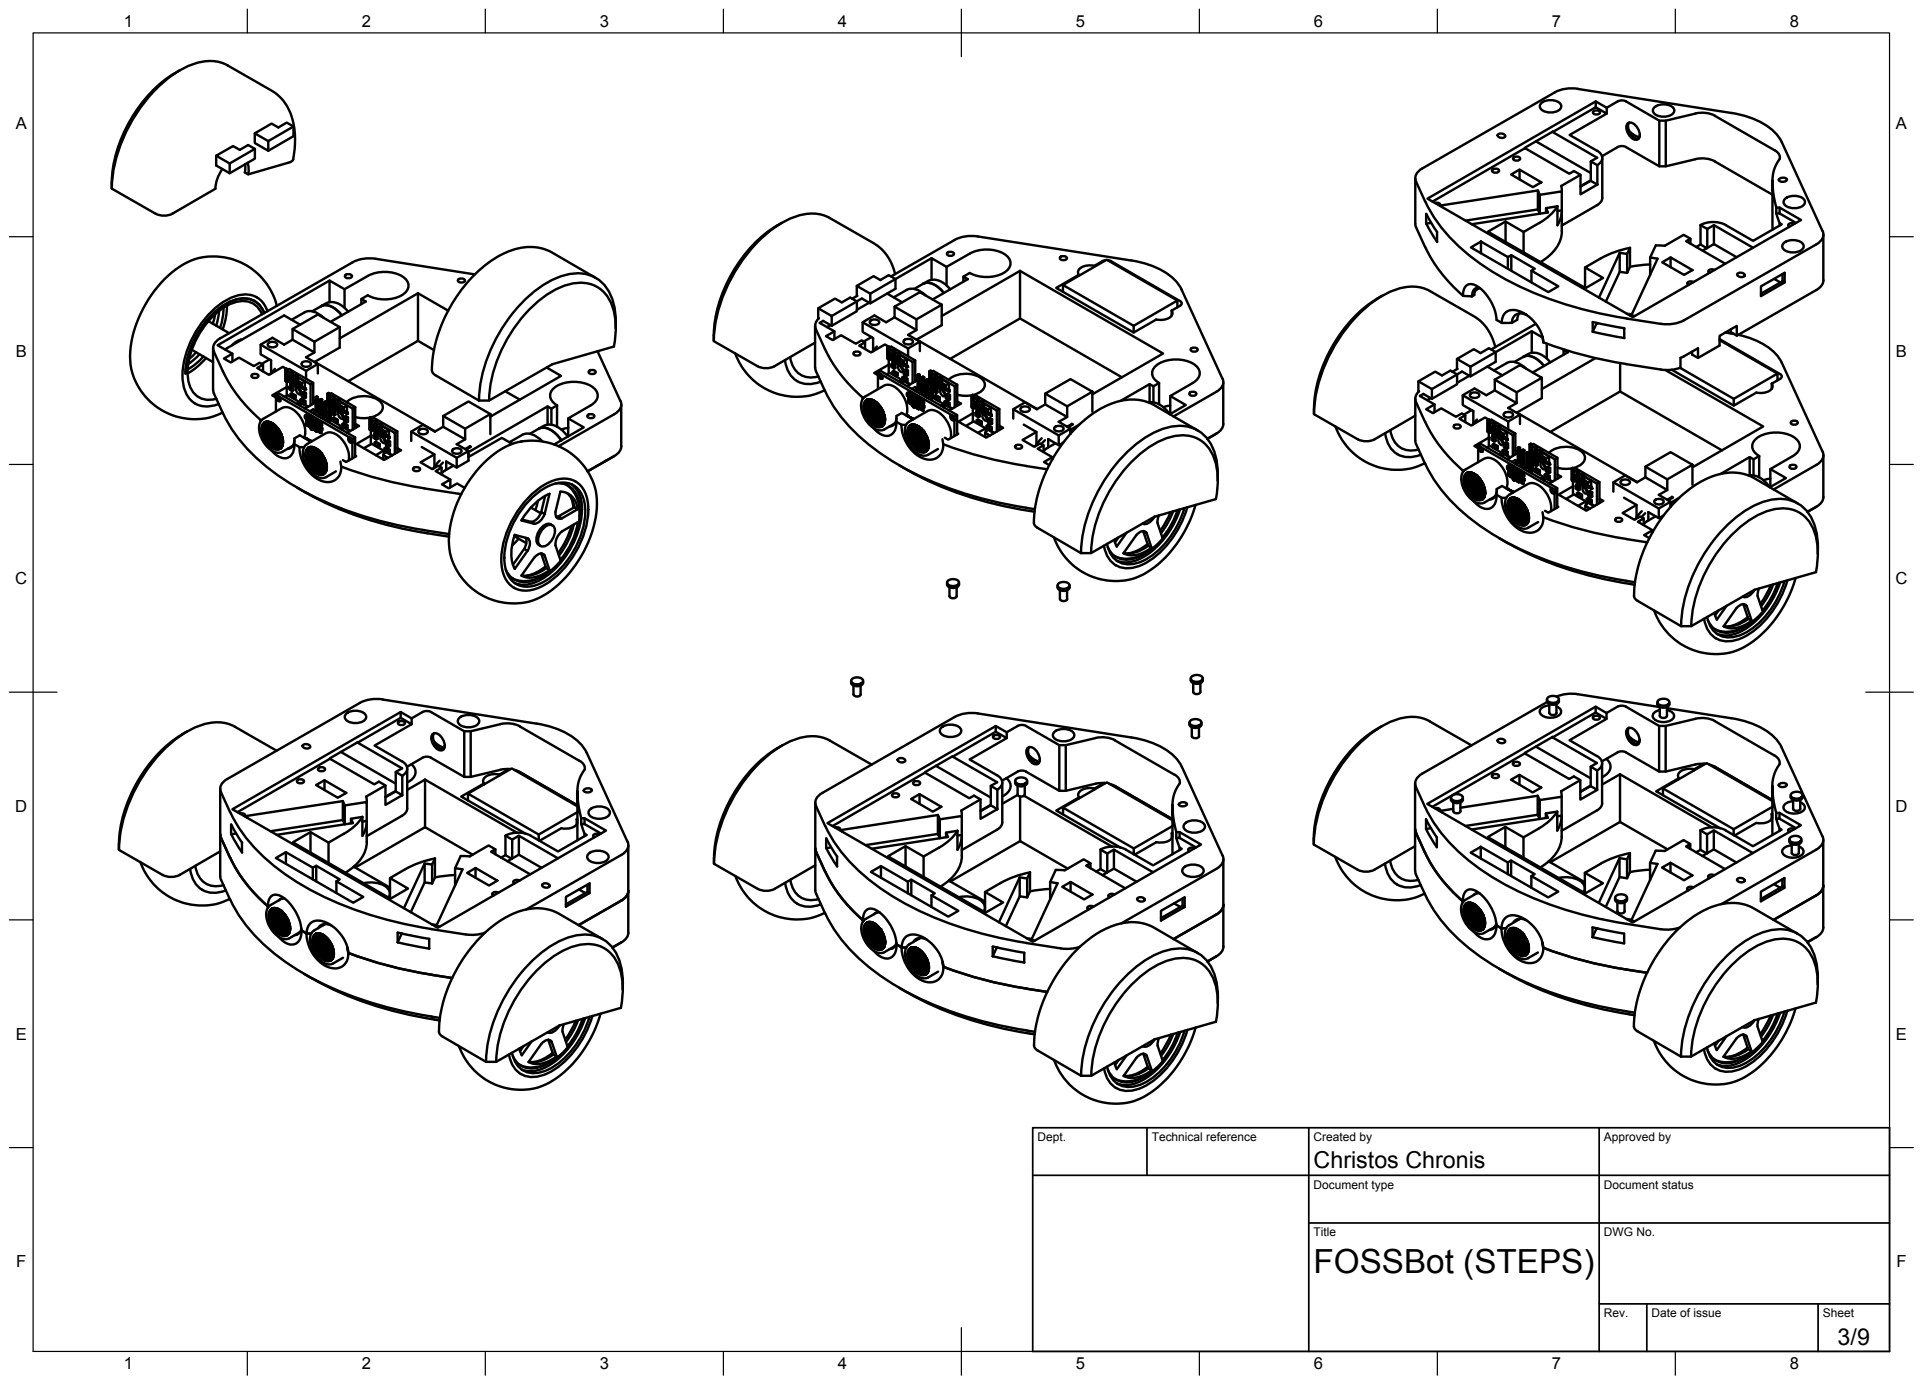
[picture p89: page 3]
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

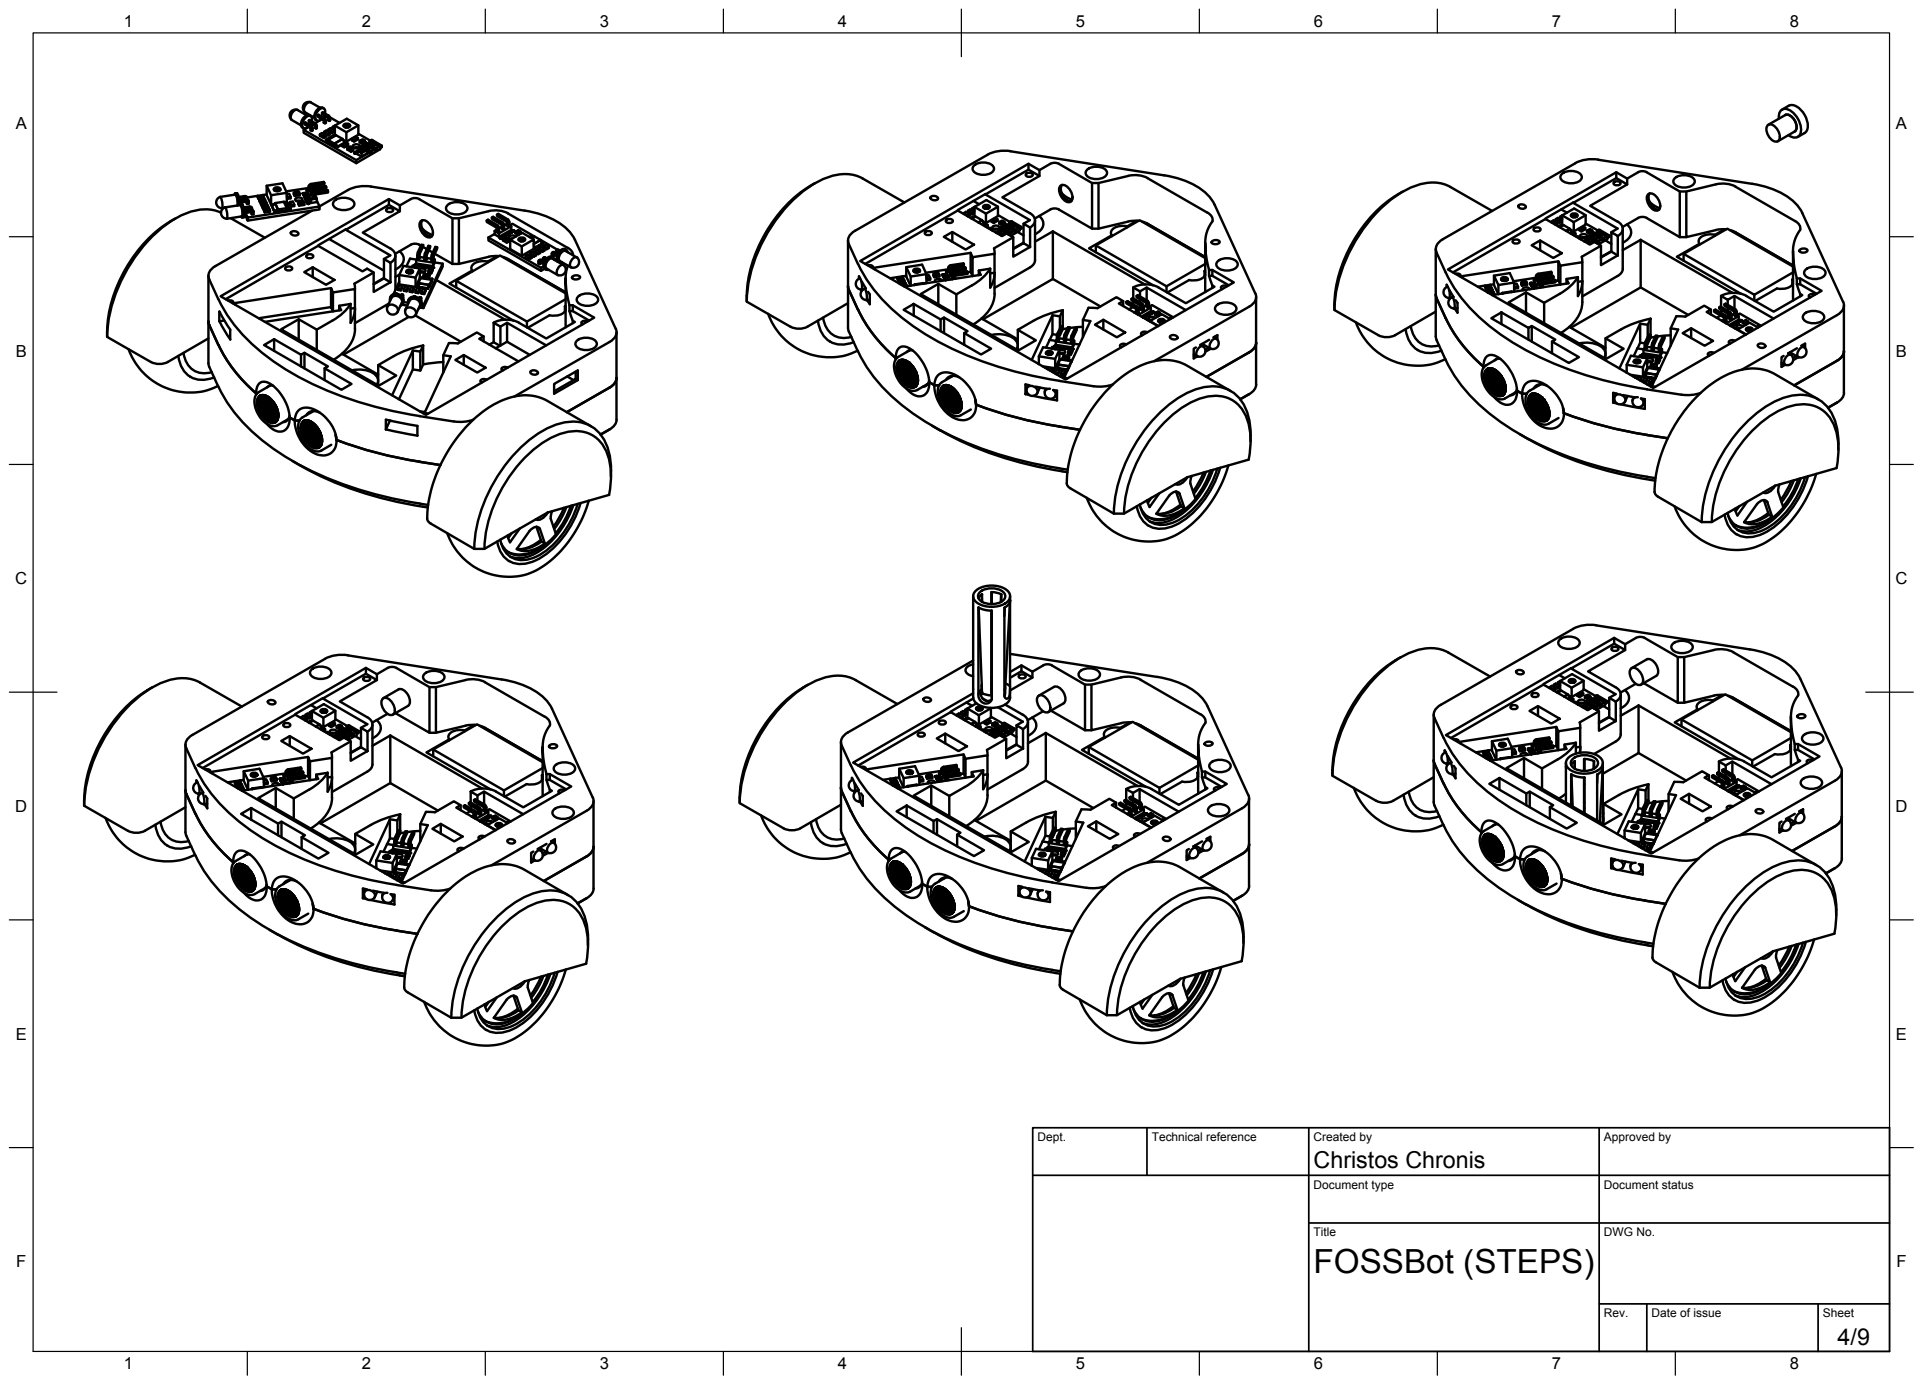
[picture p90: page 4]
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

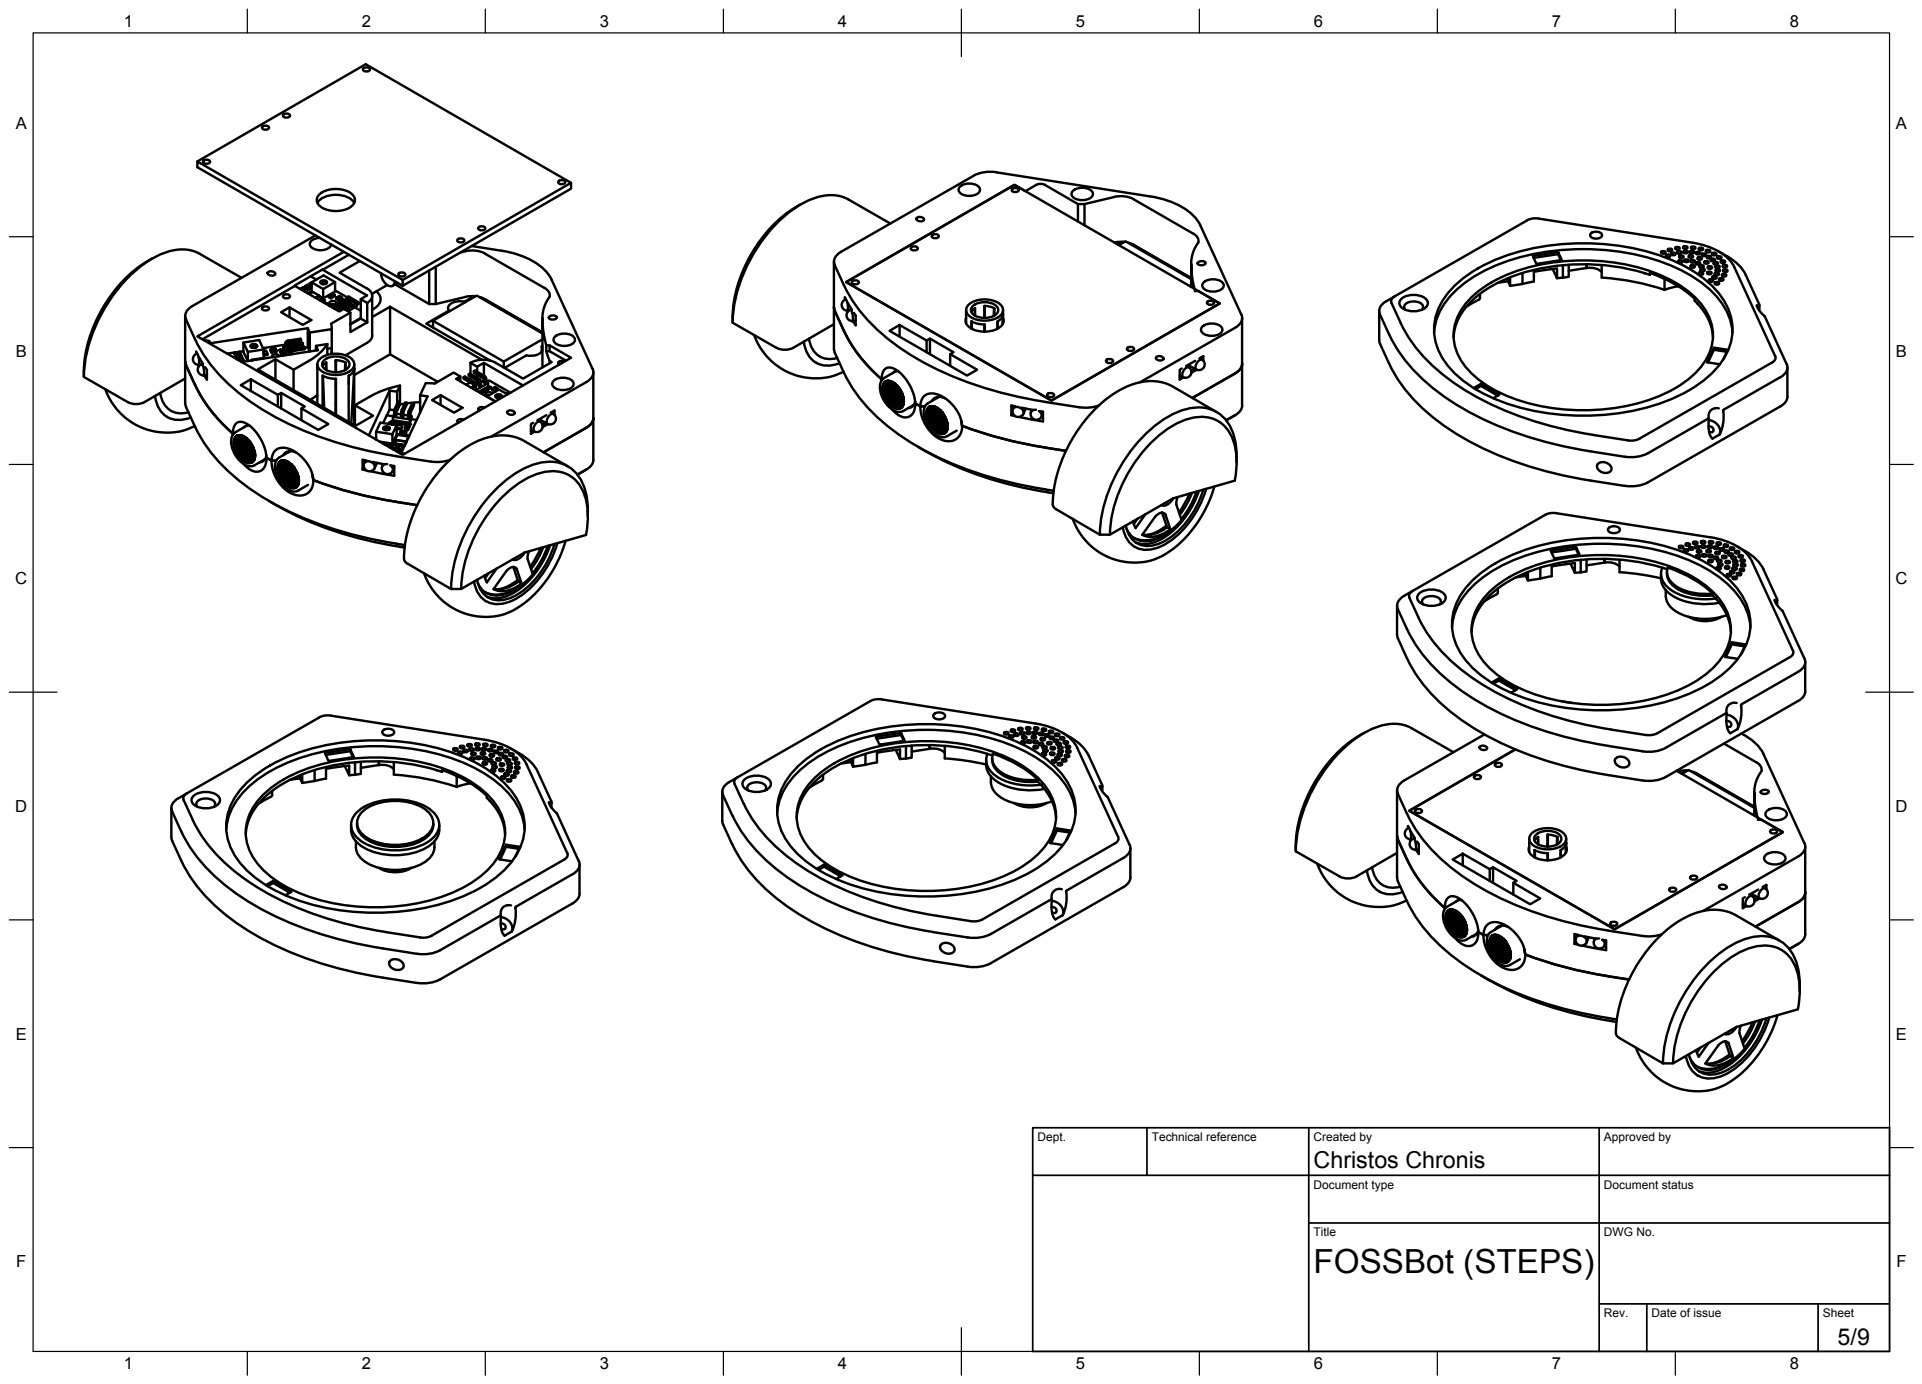
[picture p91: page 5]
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

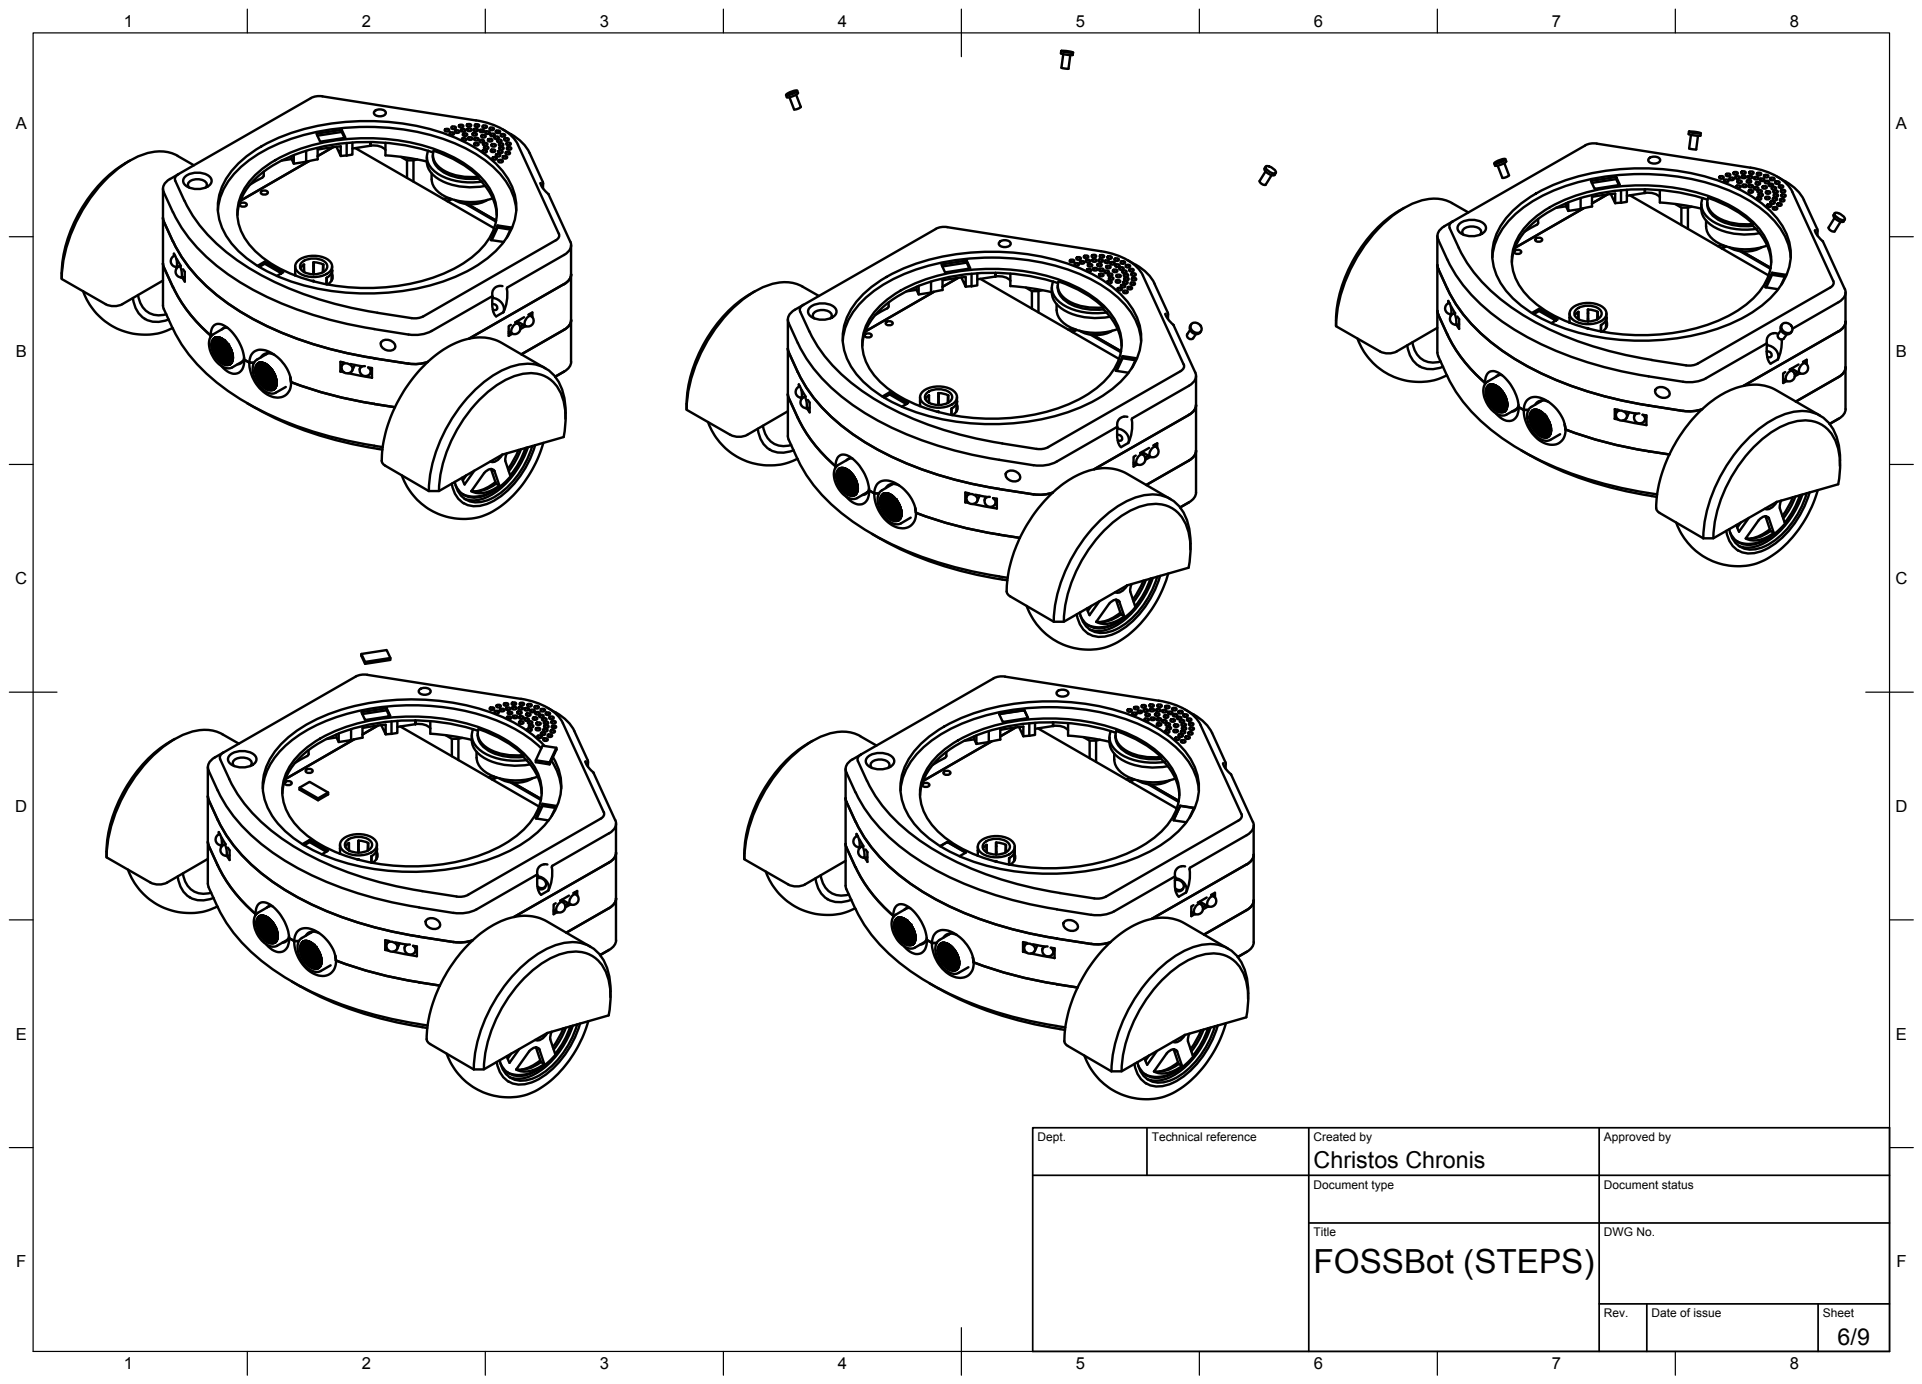
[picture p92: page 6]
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

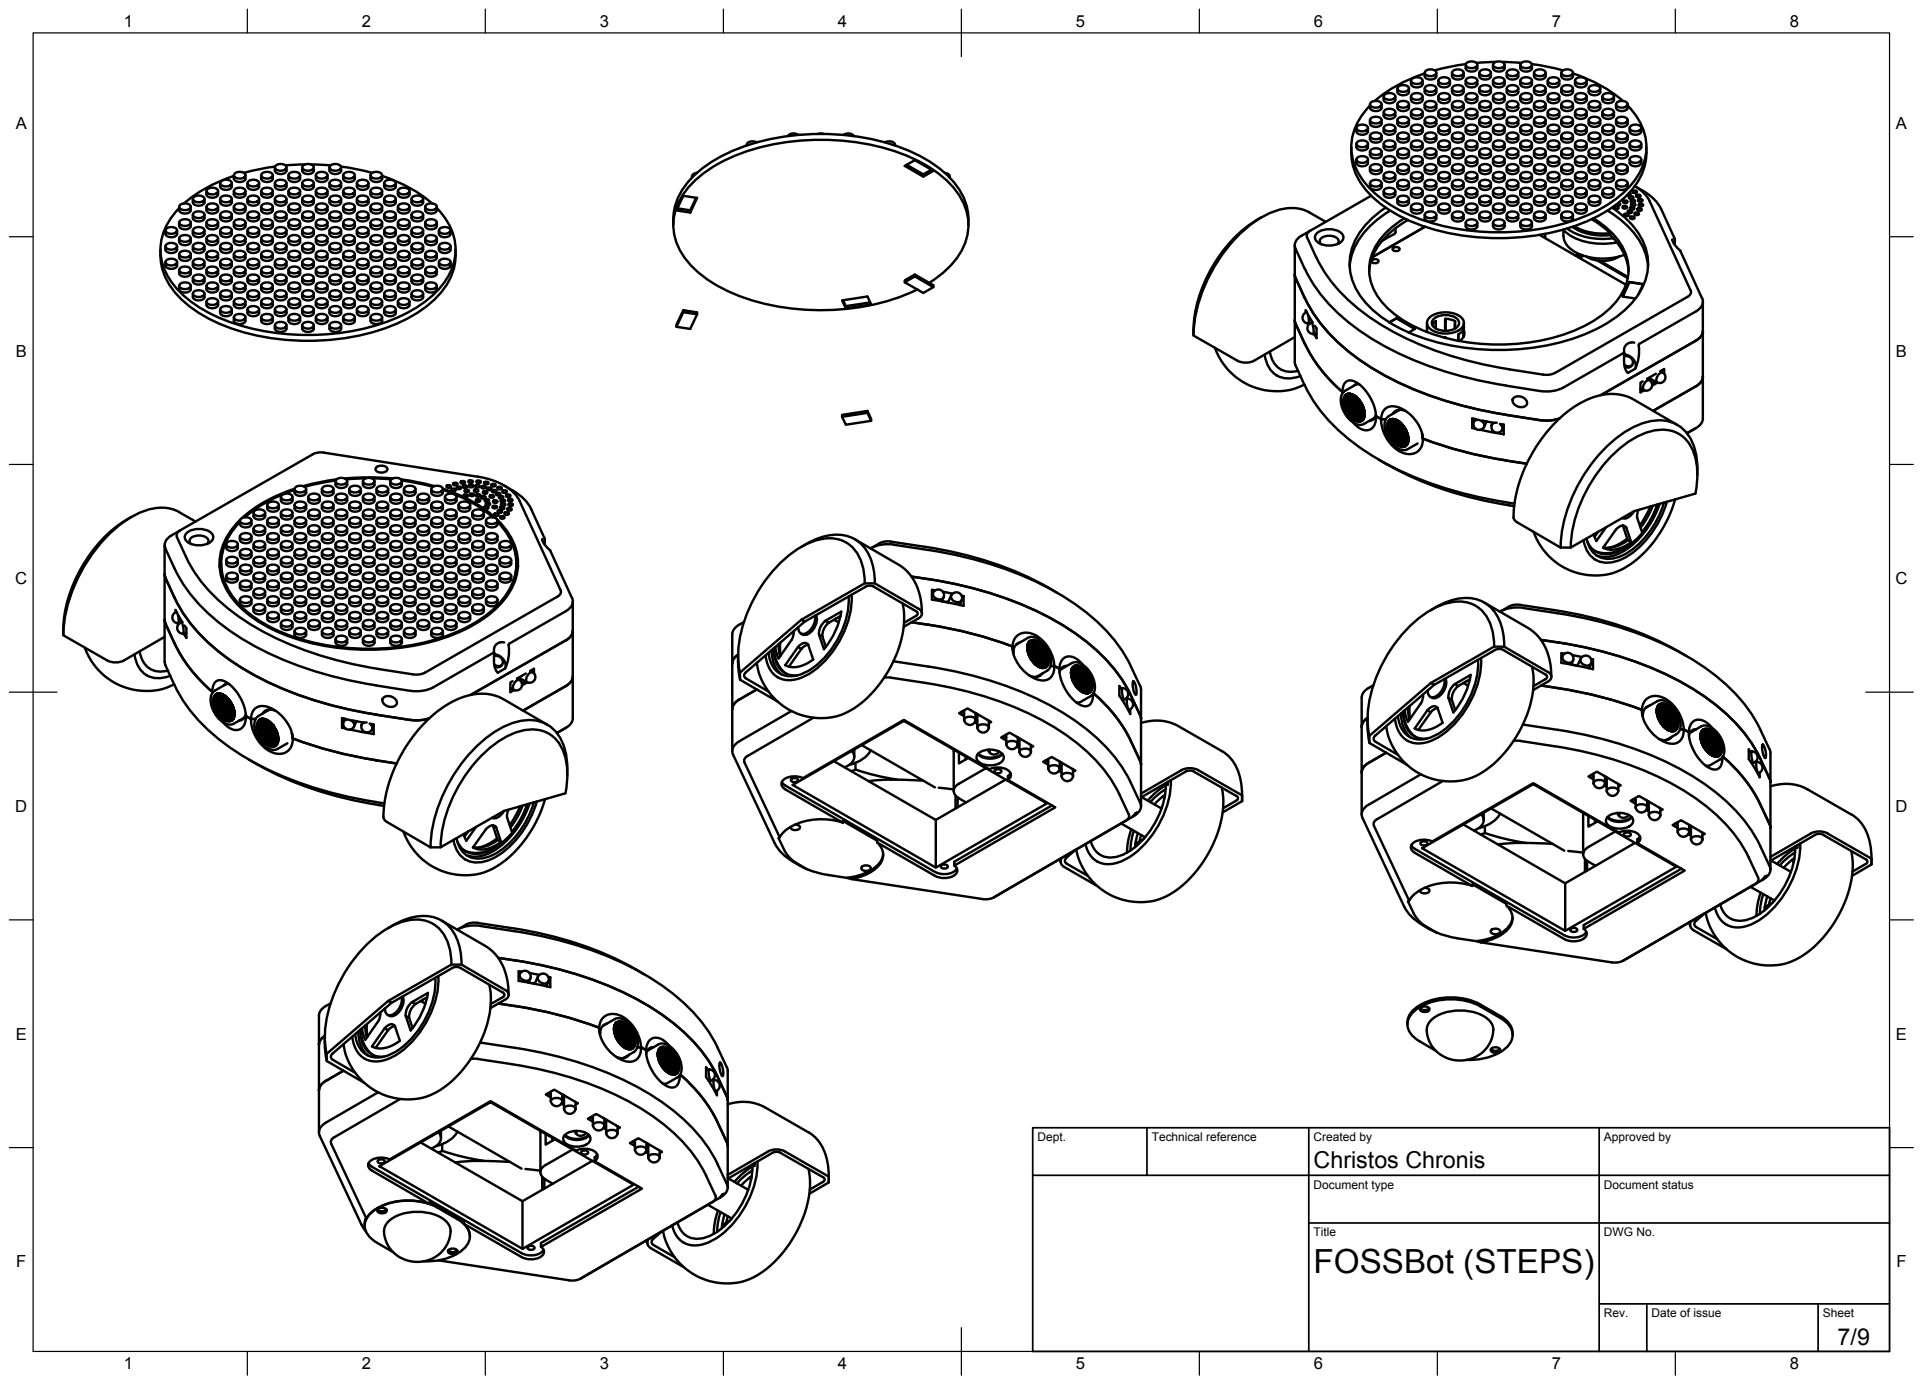
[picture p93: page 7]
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

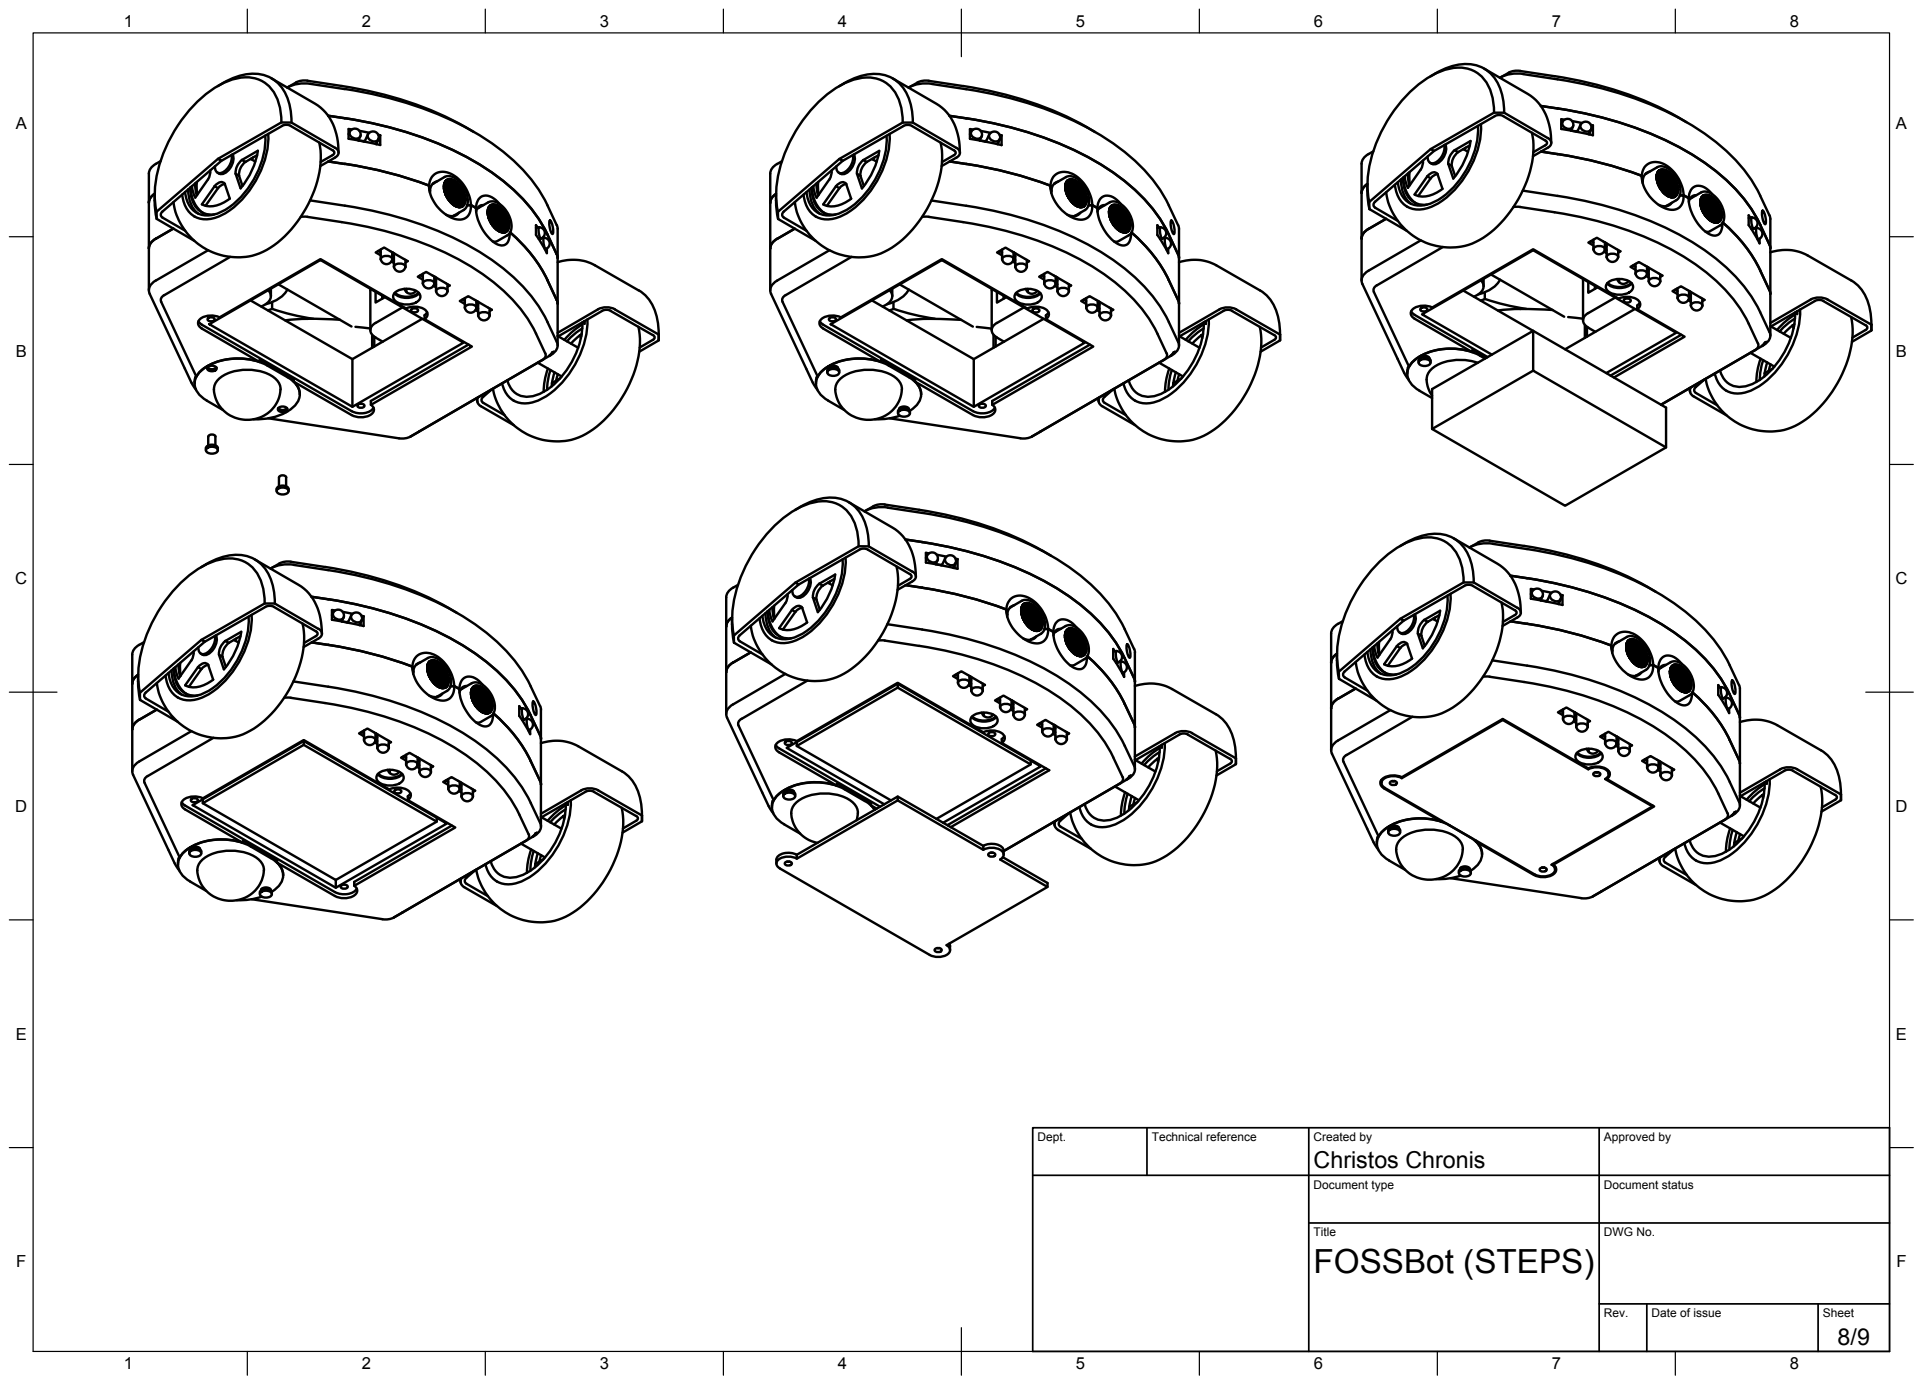
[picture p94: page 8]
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

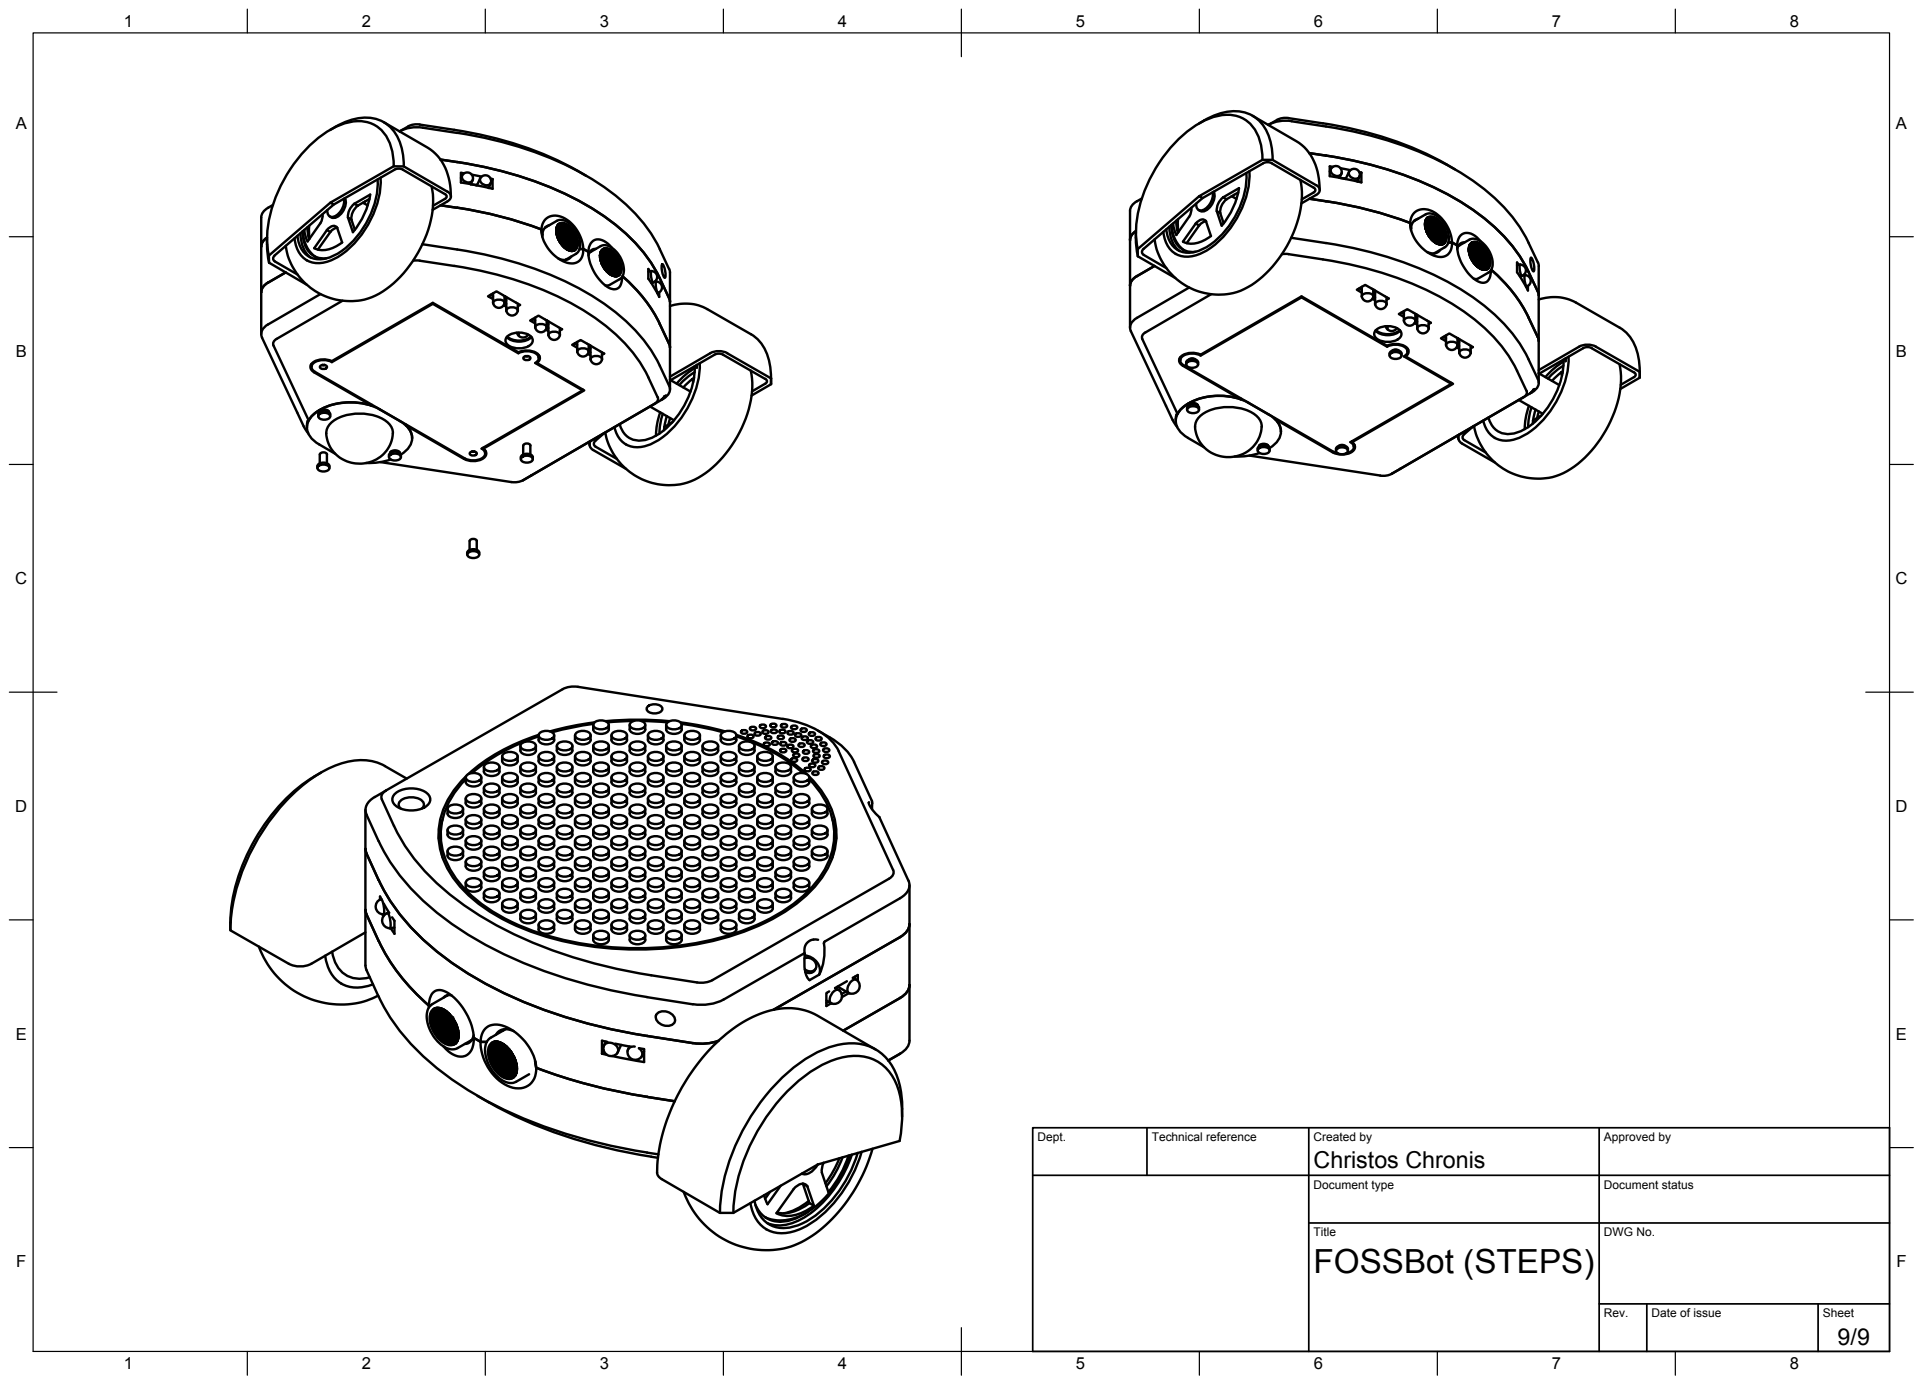
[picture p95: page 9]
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

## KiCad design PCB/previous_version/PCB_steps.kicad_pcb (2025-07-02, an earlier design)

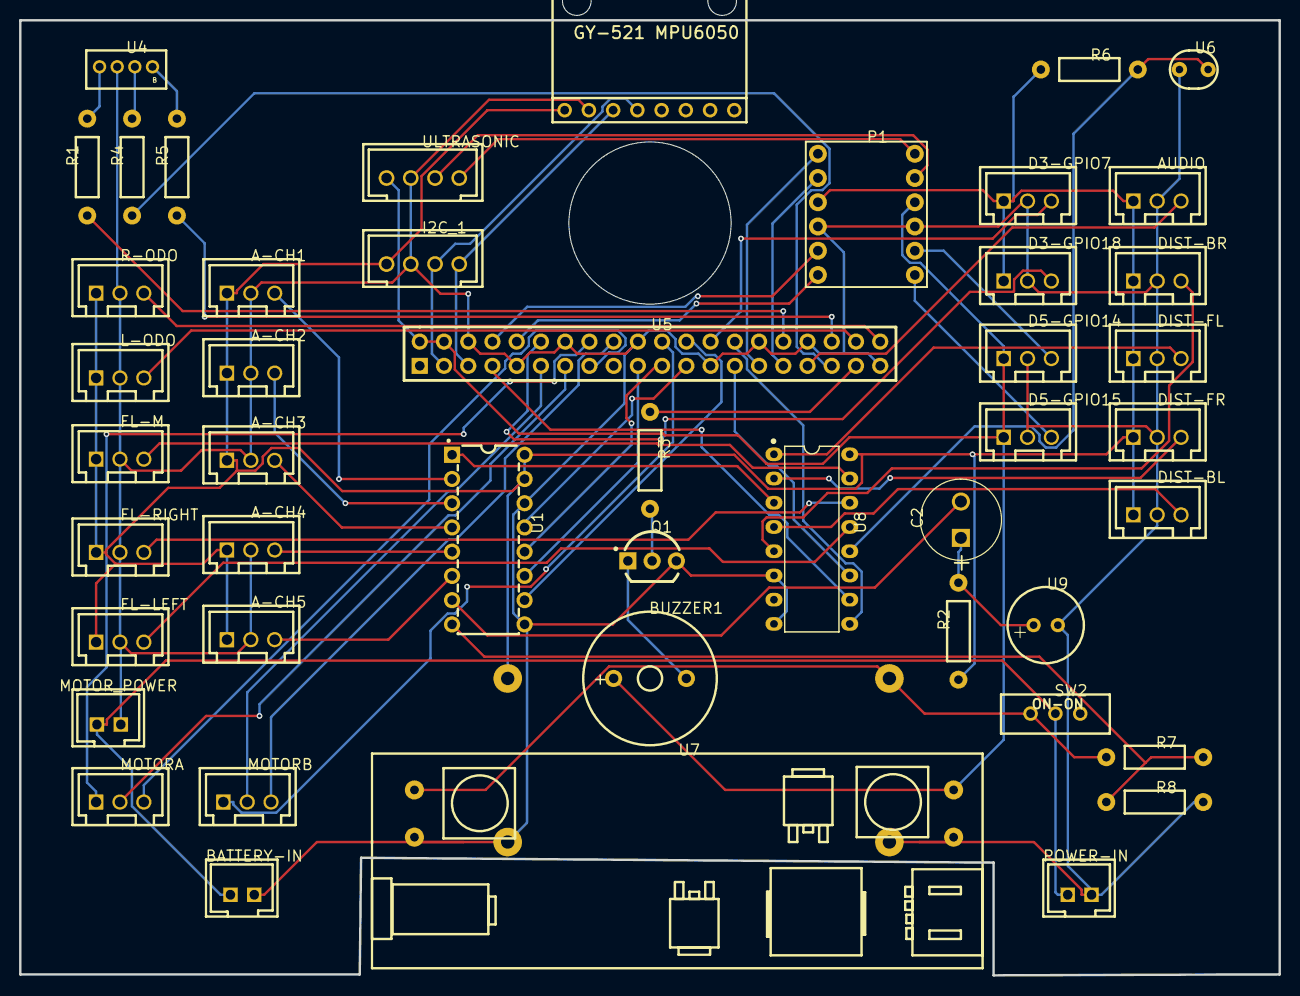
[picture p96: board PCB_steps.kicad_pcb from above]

Board: 2 copper layers, 132.0 x 100.1 mm, 48 parts (0 on the bottom side), 59 nets.

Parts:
A-CH1, A-CH2, A-CH3, A-CH4, A-CH5: HCZZ0126-3; CONN-TH_3P-P2.50_3PIN
AUDIO: HCZZ0126-3; CONN-TH_3P-P2.50_3PIN
BATTERY-IN: XH2.54-2PIN-直针; CONN-TH_XH2.54-2P
BUZZER1: FSD-1407B-12V; BUZ-TH_BD14.0-P7.60-D0.7-FD
C2: 1µF; ELECTRO-8.6MM
D3-GPIO7, D3-GPIO18, D5-GPIO14, D5-GPIO15: HCZZ0126-3; CONN-TH_3P-P2.50_3PIN
DIST-BL: HCZZ0126-3; CONN-TH_3P-P2.50_3PIN
DIST-BR: HCZZ0126-3; CONN-TH_3P-P2.50_3PIN
DIST-FL: HCZZ0126-3; CONN-TH_3P-P2.50_3PIN
DIST-FR: HCZZ0126-3; CONN-TH_3P-P2.50_3PIN
FL-LEFT: HCZZ0126-3; CONN-TH_3P-P2.50_3PIN
FL-M: HCZZ0126-3; CONN-TH_3P-P2.50_3PIN
FL-RIGHT: HCZZ0126-3; CONN-TH_3P-P2.50_3PIN
I2C_1: HCZZ0126-4; CONN-TH_XH2.54-4P
L-ODO: HCZZ0126-3; CONN-TH_3P-P2.50_3PIN
MOTORA: HCZZ0126-3; CONN-TH_3P-P2.50_3PIN
MOTORB: HCZZ0126-3; CONN-TH_3P-P2.50_3PIN
MOTOR_POWER: XH2.54-2PIN-直针; CONN-TH_XH2.54-2P
P1: Logic_Level Bidirectional; LOGIC_LEVEL BIDIRECTIONAL
POWER-IN: XH2.54-2PIN-直针; CONN-TH_XH2.54-2P
Q1: 2N2222A; TO-92-3 (NPN)_L4.8-W3.7-P2.54-R
R1, R4, R5: 270Ω; AXIAL-0.4
R2: 2.2KΩ; AXIAL-0.4
R3, R8: 1KΩ; AXIAL-0.4
R6: 10KΩ; AXIAL-0.4
R7: 3KΩ; AXIAL-0.4
R-ODO: HCZZ0126-3; CONN-TH_3P-P2.50_3PIN
SW2: 3-Pin SPDT Slide Switch; 3-PIN SPDT SLIDE SWITCH_
U1: MCP3008-I/P; PDIP-16_L19.3-W6.5-P2.54-LS7.6-BL
U2: GY521; GY521 MPU6050
U3: DC-DC LM2596S; DC-DC LM2596S-ADJ
U4: RGB_LED_Common_Cathod; RGB-LED-TH-COMMON-CATHODE
U5: Raspberry PI 4 (HEADER 44PINS); RASPBERRY PI 4 2*40 PIN FEMALE
U6: LDR; LDR (LDRSC058S)
U7: HCW-P715
U8: TC74HC4051APF; PDIP-16_L19.3-W6.4-P2.54-LS7.94-BL
U9: MicroPhone; MICROPHONE
ULTRASONIC: HCZZ0126-4; CONN-TH_XH2.54-4P

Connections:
CH0: U1.1, U8.3
CH6: C2.-, U1.7
CH7: R7.2, R8.1, U1.8
CLK: U1.13, U5.23
CS: U1.10, U5.24
DIN: U1.11, U5.19
DIST-BL_3: DIST-BL.3, U8.4
DIST-BR_3: DIST-BR.3, U8.5
DIST-FL_3: DIST-FL.3, U8.1
DIST-FR_3: DIST-FR.3, U8.2
DOUT: U1.12, U5.21
FL-LEFT_3: FL-LEFT.3, U8.13
FL-M_3: FL-M.3, U8.15
FL-RIGHT_3: FL-RIGHT.3, U8.14
GND: A-CH1.2, A-CH2.2, A-CH3.2, A-CH4.2, A-CH5.2, AUDIO.2, BATTERY-IN.2, D3-GPIO7.2, D3-GPIO18.2, D5-GPIO14.2, D5-GPIO15.2, DIST-BL.2, DIST-BR.2, DIST-FL.2, DIST-FR.2, FL-LEFT.2, FL-M.2, FL-RIGHT.2, I2C_1.2, L-ODO.2, MOTOR_POWER.2, P1.4, P1.9, POWER-IN.2, Q1.3, R8.2, R-ODO.2, U1.9, U1.14, U2.2, U3.2, U3.3, U4.GND, U5.6, U5.9, U5.14, U5.20, U5.25, U5.30, U5.34, U5.39, U6.1, U7.2, U7.3, U8.6, U8.8, U9.2, ULTRASONIC.2
GPIO0: U5.27, U8.11
GPIO1: U5.28, U8.9
GPIO4: U5.7, U8.10
GPIO5: P1.12, U5.29
GPIO6: P1.11, U5.31
GPIO7: D3-GPIO7.3, U5.26
GPIO12: R1.1, U5.32
GPIO13: AUDIO.3, U5.33
GPIO14: P1.8, U5.8
GPIO15: P1.7, U5.10
GPIO16: R5.1, U5.36
GPIO17: MOTORB.2, U5.11
GPIO18: D3-GPIO18.3, U5.12
GPIO19: R4.1, U5.35
GPIO20: L-ODO.3, U5.38
GPIO21: R-ODO.3, U5.40
GPIO22: MOTORA.3, U5.15
GPIO23: MOTORA.1, U5.16
GPIO24: MOTORB.3, U5.18
GPIO25: MOTORB.1, U5.22
GPIO26: R3.1, U5.37
GPIO27: MOTORA.2, U5.13
LDR: R6.2, U6.2, U8.12
P1_1: P1.1, ULTRASONIC.4
P1_2: P1.2, ULTRASONIC.3
P1_5: D5-GPIO14.3, P1.5
P1_6: D5-GPIO15.3, P1.6
Q1_1: BUZZER1.2, Q1.1
Q1_2: Q1.2, R3.2
R1_2: R1.2, U4.R
R4_2: R4.2, U4.G
R5_2: R5.2, U4.B
SCL: I2C_1.4, U2.3, U5.5
SDA: I2C_1.3, U2.4, U5.3
SW12V: R7.1, SW2.ON_1, U3.4, U7.1
U1_2: A-CH1.3, U1.2
U1_3: A-CH2.3, U1.3
U1_4: A-CH3.3, U1.4
U1_5: A-CH4.3, U1.5
U1_6: A-CH5.3, U1.6
U9_1: C2.+, R2.2, U9.1
VCC: A-CH1.1, A-CH2.1, A-CH3.1, A-CH4.1, A-CH5.1, AUDIO.1, D3-GPIO7.1, D3-GPIO18.1, DIST-BL.1, DIST-BR.1, DIST-FL.1, DIST-FR.1, FL-LEFT.1, FL-M.1, FL-RIGHT.1, I2C_1.1, L-ODO.1, P1.10, R2.1, R6.1, R-ODO.1, U1.15, U1.16, U2.1, U3.1, U8.16
VCC5V: BUZZER1.1, D5-GPIO14.1, D5-GPIO15.1, P1.3, U5.2, U5.4, U7.4, ULTRASONIC.1
VCC12V: BATTERY-IN.1, MOTOR_POWER.1, POWER-IN.1, SW2.GND

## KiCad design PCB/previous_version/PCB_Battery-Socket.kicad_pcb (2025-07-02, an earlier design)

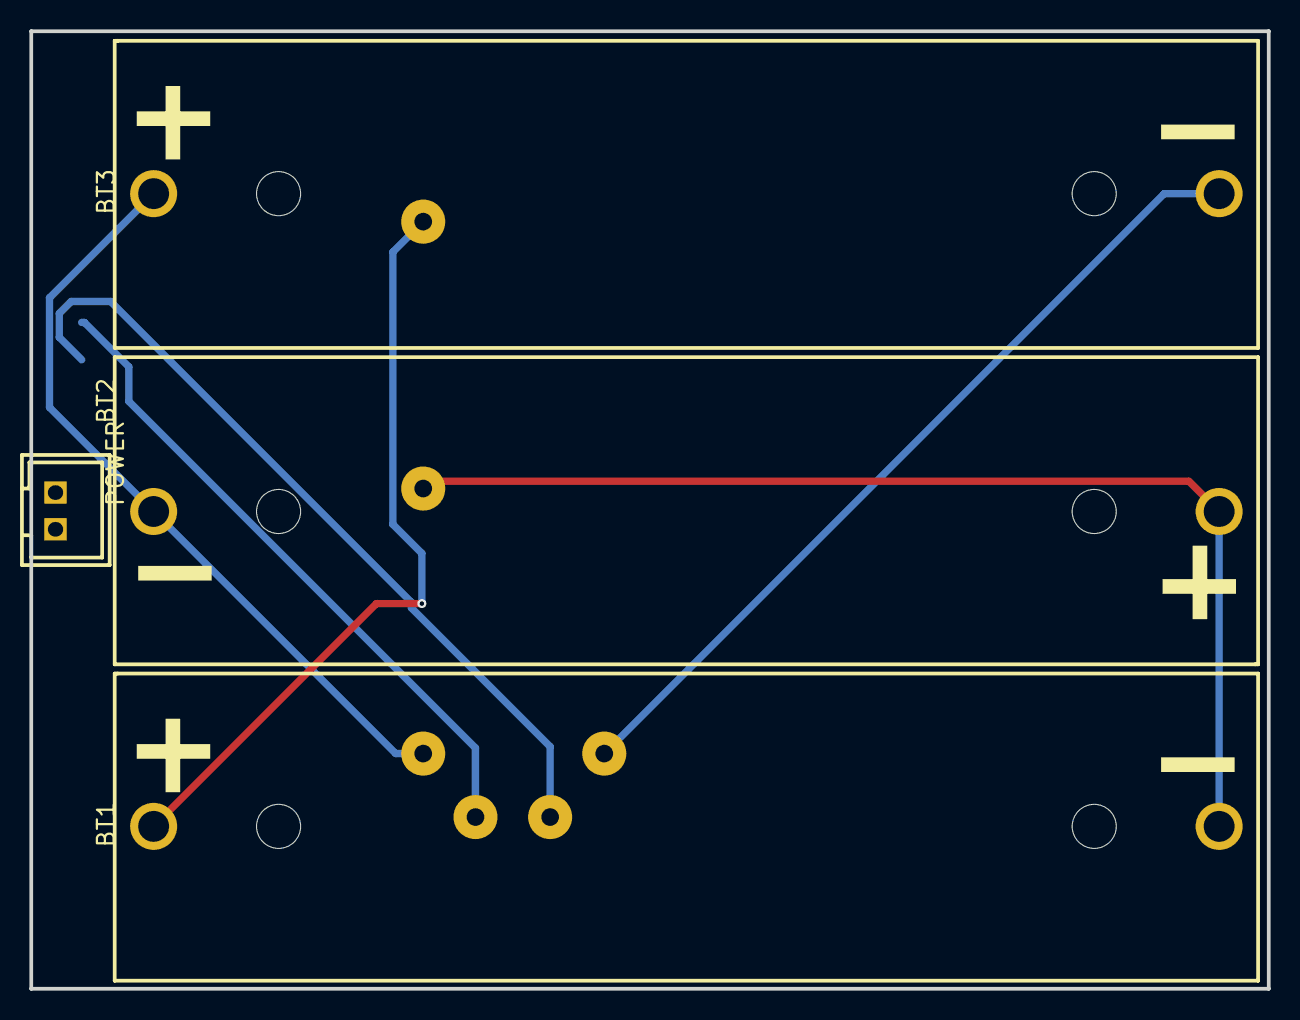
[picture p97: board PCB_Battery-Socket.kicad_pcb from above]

Board: 2 copper layers, 84.2 x 65.2 mm, 5 parts (0 on the bottom side), 6 nets.

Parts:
BMS1: HX-3S-01
BT1, BT2, BT3: BH-18650-A5BJ001; BAT-TH_18650-A5BJ001
POWER: XH2.54-2PIN-直针; CONN-TH_XH2.54-2P

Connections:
BMS1_5: BMS1.5, POWER.2
BMS1_6: BMS1.6, POWER.1
BT1_1: BMS1.1, BT1.1
BT2_1: BMS1.2, BT1.2, BT2.1
BT3_1: BMS1.3, BT2.2, BT3.1
BT3_2: BMS1.4, BT3.2

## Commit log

2024-02-27 instruction for sensors and hardware diagnostics
2024-06-04 new instructions and schematics
2025-02-21 fosssbot new designs
    [battery_cover.stl, bbase.stl, mbase.stl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]
2025-02-21 fossbot new designs
    [pen_holder.stl]
2025-02-21 Update README with new FOSSBot version details and 3D printable part list
    [battery_cover.stl, bbase.stl, hanger.stl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]
2025-02-24 robot schematics
    [BOM_Battery.csv, BOM_steps_pcb.csv]
2025-06-09 Rename PR4 - Instruction manual for the assembly and programming of S.T.E.P.S. educational robot.docx.pdf to PR4 - Instruction manual for the assembly and programming of S.T.E.P.S. educational robot.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
2025-07-02 pcb files for kickad and easyeda
    [BOM_Battery.csv, BOM_steps_pcb.csv, PCB_Battery-Socket.kicad_pcb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]
2026-01-26 new designs
    [PCB_Battery-Socket.kicad_pcb, PCB_steps.kicad_pcb, b1_p_f.stl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]
2026-01-26 new pcb images
2026-01-26 Update README with PCB production files
    Added PCB production files and images to README.
2026-01-26 Add eye STL files and images to README
2026-02-02 fix pcb base
    [b2_p_f.stl]
2026-02-04 power override
